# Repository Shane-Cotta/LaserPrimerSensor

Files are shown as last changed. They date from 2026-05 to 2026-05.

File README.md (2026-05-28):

# Laser Primer Sensor

A DIY fiber-optic **primer orientation / presence sensor** for the **Mark 7 Apex 10** progressive reloading press. The sensor head watches the priming station from beneath the shell plate; if a primer is missing or sitting wrong, the amplifier flips its output and signals the press to stop before it indexes to the next station.

It's a DIY alternative to a commercial primer sensor, built from off-the-shelf parts and **two 3D-printed housings**:

- **Fiber Module Housing** — holds the RS320-TZ-M3 fiber head and mounts **under the shell plate**, aimed at the priming station.
- **In-Line Module Housing** — the electronics enclosure (amplifier, boost converter, opto-isolator). It mounts remotely — **zip-tied to the case feeder pole** or simply **set on the workbench** near the press — with the fiber and signal cable running back to the fiber head and the press.

> ⚠️ **This is a hobbyist project shared as-is, with no warranty.** A DIY sensor is a backstop, not a substitute for safe reloading practice and visual inspection. Test thoroughly with dummy/empty cases before live loading, and follow Mark 7's guidance for wiring anything into your press. You are responsible for your own machine and your own safety.

---

## How it works

The **RS320-TZ-M3** right-angle fiber head is a diffuse-reflective probe: it emits light from one fiber and reads the light bounced back into the other. A correctly seated, right-side-up primer reflects a different amount of light than an empty pocket or an upside-down/missing primer.

The **FS-N18** amplifier reads that reflected intensity as a 0–9999 value and compares it to a threshold. Run in **Dark-ON** mode with a threshold around **3950** (your tuned value), it switches its output based on whether the reflected light is above or below the set point. That output is passed through a **PC817 opto-isolator** — which galvanically isolates the sensor from the press electronics — and then into the Apex 10's sensor/stop input.

The **XL6019** boost converter takes the Apex 10 / AutoDrive board's **5 V** and steps it up to the **12 V** the FS-N18 needs. The amplifier's output is **NPN** (open-collector, switching to ground), and the **PC817 opto-isolator** bridges that 12 V signal back down to the board's 5 V SIGNAL terminal using an internal light path — so there's no direct electrical connection between the sensor side and the press electronics.

---

## Bill of materials

| # | Part | Qty | Notes |
|---|---|-----|---|
| 1 | BOJKEON **FS-N18** dual-display fiber optic amplifier — [link](https://www.amazon.com/dp/B0DMW48CJ2) | 1 | 12–24 VDC, NPN/PNP open-collector output |
| 2 | **RS320-TZ-M3** diffuse-reflection 90° right-angle fiber head, M3 thread, 2 m lead — [link](https://www.amazon.com/dp/B0D56JZ92R) | 1 | Emit + receive fibers |
| 3 | **XL6019** 5 A adjustable DC-DC step-up (boost) module (3-pack) — [link](https://www.amazon.com/dp/B082XQC2DS) | 1 | Sets supply voltage for the amplifier |
| 4 | NOYITO **PC817** 1-channel optocoupler isolation module (12 V input version) — [link](https://www.amazon.com/dp/B0B5383L69) | 1 | Isolates the 12 V sensor signal back to the board's 5 V SIGNAL terminal |
| 5 | **In-Line Module Housing** (3D printed) | 1 | Electronics box — `hardware/In-Line_Module_Housing.step` |
| 6 | **Fiber Module Housing** (3D printed) | 1 | Holds fiber head under shell plate — `hardware/Fiber_Module_Housing.step` |
| 7 | Power | — | Taken from the **Apex 10 / AutoDrive 5 V** output (no separate adapter in the standard setup) |
| 8 | 3-pin terminal / cable to the AutoDrive sensor port | 1 | Carries 5 V, GND, and SIGNAL between the box and the board |
| 9 | Zip ties | a few | To mount the In-Line box to the case feeder pole (optional) |

**Fasteners**
- **PCB mounting (inside housing):** standard **HDD/SSD chassis screws** (6-32 / M3-class drive screws)
- **Case plate / lid:** **M4** screws
- **Fiber head:** **M3** thread (built into the RS320-TZ-M3 head; threads into the Fiber Module Housing)

> The components are third-party products sold under their own terms. This project only covers the custom housings, wiring, and documentation.

---

## 1. Print the housings

Two parts to print, both provided as STEP files (modeled in millimeters):

- `hardware/In-Line_Module_Housing.step` — the electronics box (FS-N18, XL6019, PC817)
- `hardware/Fiber_Module_Housing.step` — the under-shell-plate mount that holds the RS320-TZ-M3 fiber head

- Import into your slicer (most slicers accept STEP directly; otherwise convert to STL).
- **Material:** PETG or ABS/ASA recommended for heat and proximity to the press; PLA works for bench testing.
- **Suggested settings:** 0.2 mm layers, 3–4 perimeters, 20–30% infill.
- Orient each part so the screw holes / mounting features and the fiber bore print cleanly; add supports only if your orientation requires them.
- Test-fit the boards, the fiber head, and the screws before final assembly; tune your slicer's hole/horizontal-expansion compensation if anything comes out tight.

---

## 2. Wiring

Wiring diagram

**Signal chain:** AutoDrive 5 V → XL6019 boost (set to 12 V) → FS-N18 amplifier → (optical fiber) RS320-TZ-M3 head → primer; FS-N18 NPN output → PC817 isolator → AutoDrive SIGNAL terminal.

**5 V side — AutoDrive board to boost and opto:**

| From | To |
|---|----|
| AutoDrive 5 V out | XL6019 IN+ |
| AutoDrive 5 V out (jumper) | PC817 VCC |
| AutoDrive GND | XL6019 IN− |
| XL6019 IN− (jumper) | PC817 GND |
| PC817 OUT | AutoDrive SIGNAL in |

**12 V side — boost out to sensor and opto input:**

| From | To |
|---|----|
| XL6019 OUT+ | FS-N18 Brown (+12 V) |
| XL6019 OUT+ (jumper) | PC817 IN+ |
| XL6019 OUT− | FS-N18 Blue (0 V) |
| FS-N18 Black (NPN signal) | PC817 IN− |
| FS-N18 T ▸ / R ◂ fiber ports | RS320-TZ-M3 emit / receive fibers |

FS-N18 cable colors: **Blue = 0 V**, **Brown = +12 V**, **Black = signal output**.

Physical reference — internal wiring of the assembled unit:

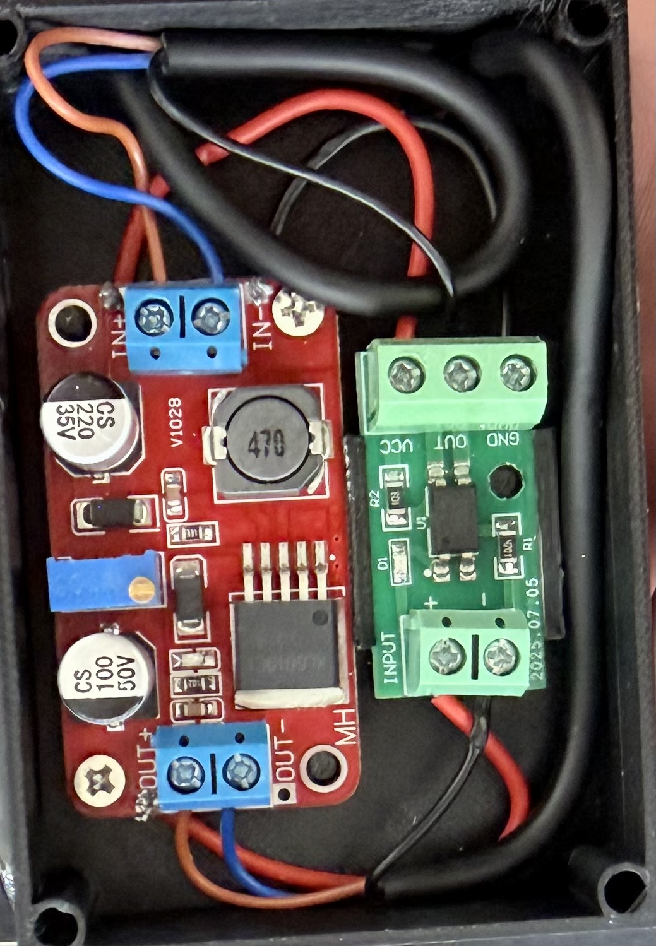
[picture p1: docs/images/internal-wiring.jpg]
Internal wiring


> ⚠️ **Confirm against your unit:** (1) that power comes from the **AutoDrive 5 V** terminal rather than a separate adapter, and (2) that the **FS-N18 output is the NPN version**. The rest of the wiring is determined by the parts.

3d reference — 3d render of the assembled pcb housing unit:
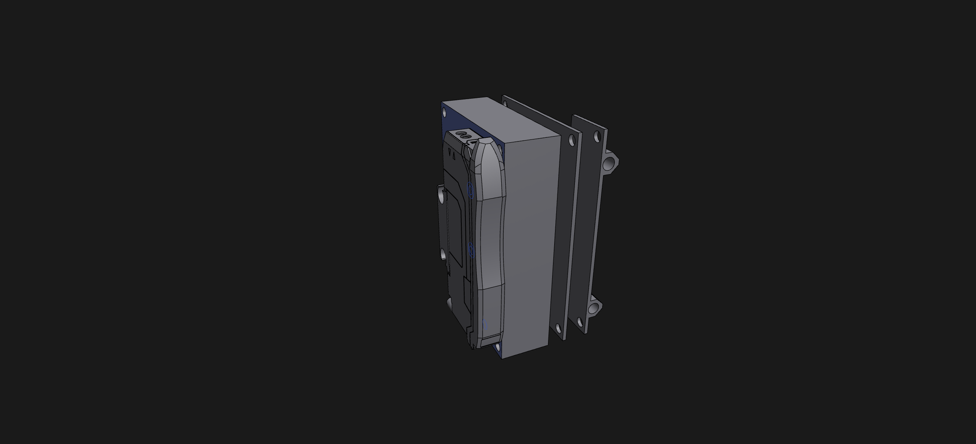
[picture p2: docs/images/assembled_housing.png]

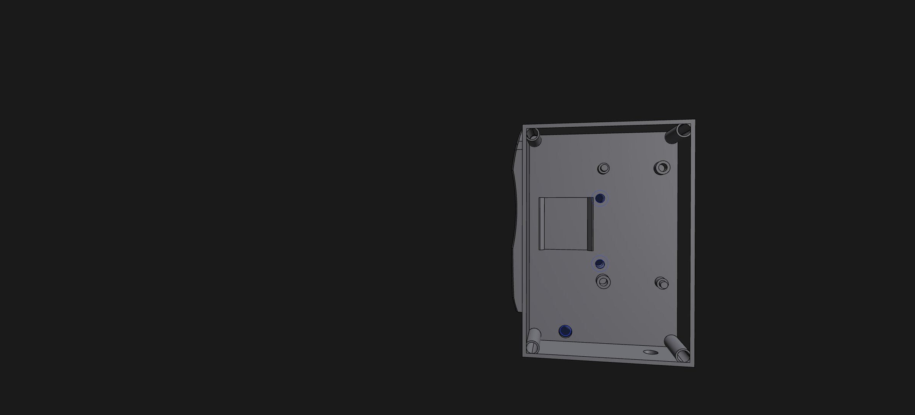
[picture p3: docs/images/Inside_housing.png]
 

3d reference — 3d render of the fiber head housing:
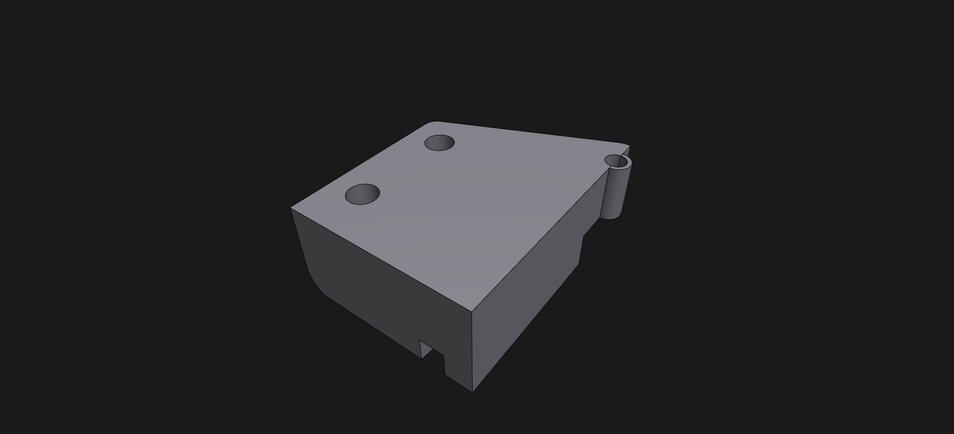
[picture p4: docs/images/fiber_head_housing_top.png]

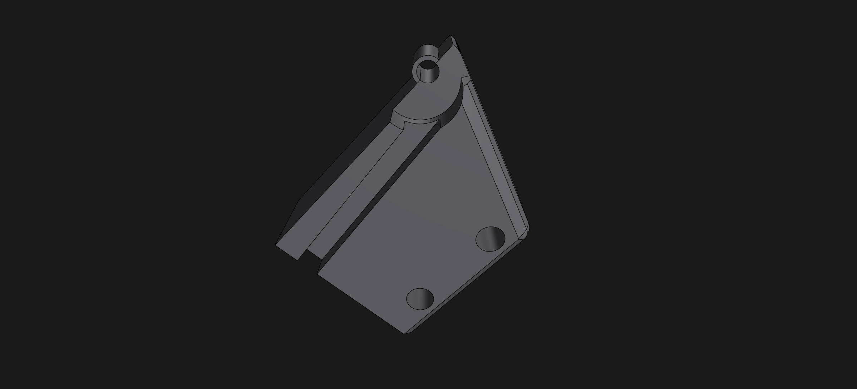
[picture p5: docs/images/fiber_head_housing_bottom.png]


Physical reference — the fiber head mounted under the shell plate, with the fiber routed back to the electronics box:
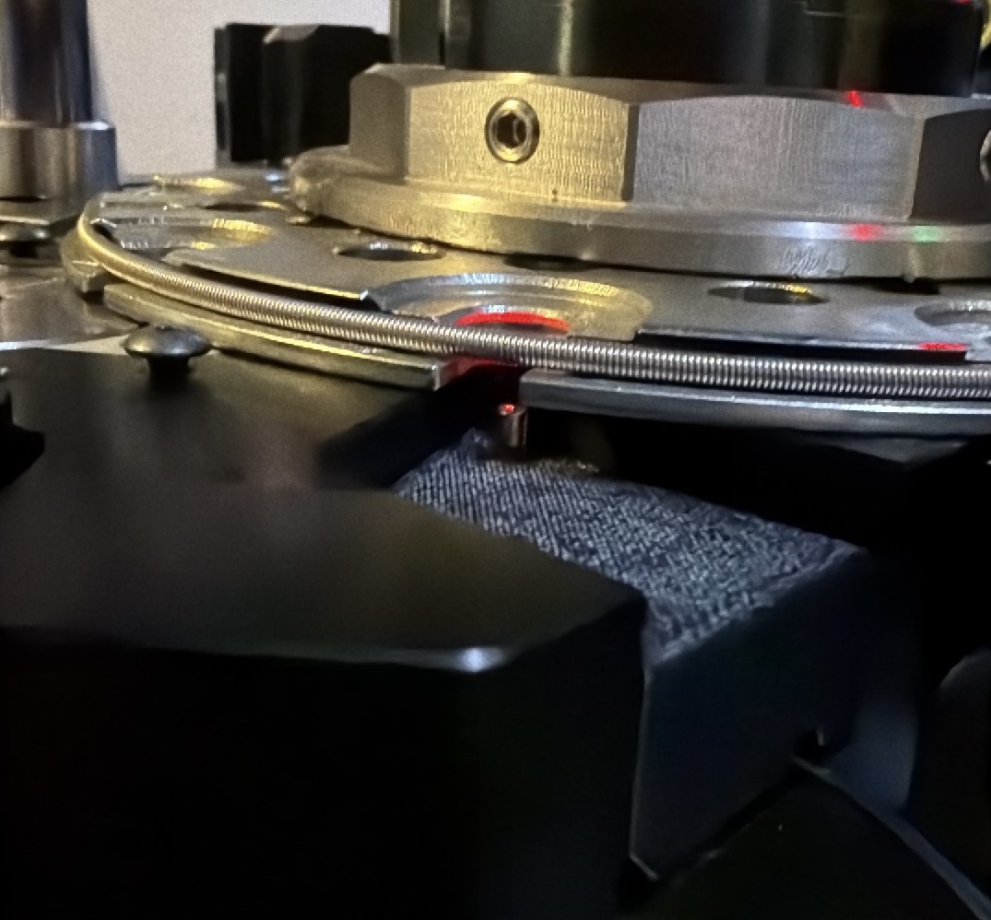
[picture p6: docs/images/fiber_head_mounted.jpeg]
Fiber head mounted


Physical reference — the assembled unit ready for mounting to the press:
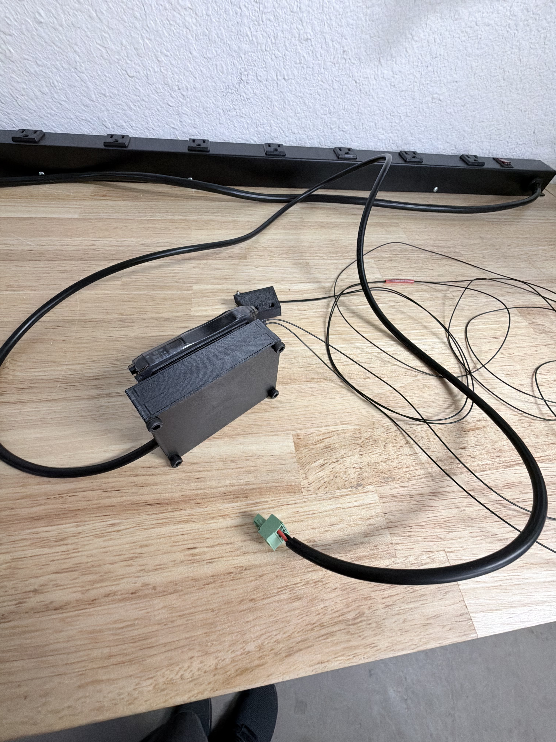
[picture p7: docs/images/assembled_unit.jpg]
Assembled unit


---

## 3. Assembly

**Electronics — In-Line Module Housing:**
1. Set the XL6019 boost output to **12.0 V before** wiring it to anything else: feed it from the AutoDrive 5 V (power the board by USB only, nothing else connected), turn the trim pot while watching a multimeter on OUT+/OUT− until it reads 12.0 V, then disconnect power. (Getting this right first prevents most wiring headaches.)
2. Mount the XL6019 and PC817 boards inside the In-Line housing using the **HDD/SSD chassis screws** into the printed bosses.
3. Seat the FS-N18 amplifier in its pocket and route its cable to the boards per the connection table.
4. Make the wiring connections (boost → amp power, amp output → opto input, opto output → press pigtail through the 2-pin terminal).
5. Insert the RS320-TZ-M3 fibers into the FS-N18's T (transmit) and R (receive) ports, following the fiber-insertion marker and locking lever on the amplifier.
6. Close the case plate and secure with the **M4** screws.

**Fiber head — Fiber Module Housing:**
7. Fit the RS320-TZ-M3 threaded fiber head into the Fiber Module Housing so the optical face points at the primer pocket; lock the standoff with the head's nut.
8. Leave enough fiber slack to route from the under-shell-plate mount back to the electronics box.

---

## 4. Mount to the Apex 10

**Fiber Module Housing (under the shell plate):**
1. Mount it beneath the shell plate so the **RS320-TZ-M3 head aims at the priming station** — where you want to confirm primer presence/orientation.
2. Secure it so the head holds a consistent, repeatable distance and angle to the primer pocket. Consistency here is everything for reliable triggering.

**In-Line Module Housing (electronics — remote):**
3. Mount the electronics box where it's convenient and out of the way: **zip-tie it to the case feeder pole**, or just set it on the bench next to the press.
4. Route the **optical fiber** from the fiber housing back to the electronics box, and the **isolated output cable** from the box to the press's sensor/stop input.
5. Keep the fiber and cables clear of moving parts and the indexing motion, with a little slack so nothing pulls tight on a stroke.

> **Eye safety:** the fiber head emits a visible beam. Don't stare into it or aim it at eye level during setup, and verify alignment with the press unpowered where you can.

---

## 5. Configure the FS-N18

Mode and threshold (general setup): **Dark-ON**, threshold ≈ **3950**. Tune to your own optics and lighting.

**Two-point teach (recommended):**
1. With **no primer / empty pocket** in front of the head, press **SET** (hold < 2 s).
2. Place a **correctly oriented primer** at the station, press **SET** again to complete.

**Other settings to dial in:**
- **Output type:** set to **NPN** (open-collector to ground) to match the PC817 input wiring and the AutoDrive board.
- **Response time (P0–P4):** faster (P0/P1) catches the primer during the brief dwell; slower modes reject noise. Match to your press speed.
- **Output mode:** Light-ON vs Dark-ON (use Dark-ON).
- **Delay/timer:** On/Off/One-shot delay (1–9999 ms) if you need to time the read to the dwell.
- **FEC (F1–F4):** if you add a second amplifier nearby, set them to different FEC channels to prevent mutual interference.
- **Keyboard lockout:** lock the keys after tuning so settings don't drift.

---

## 6. Connect to the press

The PC817 output side ties into the Apex 10's 3-pin sensor port: **OUT → SIGNAL**, **VCC → 5 V**, **GND → GND** (the same 5 V and GND that feed the boost input). A fault — missing or misoriented primer — switches the signal so the press halts before it indexes to the next station. You can disable the sensor from the Mark 7 tablet when processing brass without primers.

---

## Troubleshooting

- **No switching / value stuck:** check the boost output voltage and FS-N18 power (Brown/Blue); confirm fibers are fully seated and the lock lever is down.
- **Triggers inconsistently:** the head standoff/angle is probably varying — tighten the mount; re-run the two-point teach; nudge the threshold.
- **False trips at speed:** try a faster response mode (P0/P1) or add a short on-delay to align the read with the dwell.
- **Press doesn't see the signal:** check PC817 output polarity and that the press input is enabled and wired for the right active level.

---

## Support the Project

If this project helped you on your reloading journey, saved you some troubleshooting time, or inspired your own DIY build, and you'd like to support continued development and experimentation, you can do so here:

[Support the Project](https://donate.stripe.com/9B69AT9jK94z3j71312Ji00)

## License

This project's original work — including the custom 3D-printable housing designs, wiring diagram, photos, assembly instructions, and documentation — is licensed under the:

**Creative Commons Attribution-NonCommercial-ShareAlike 4.0 International License (CC BY-NC-SA 4.0)**

You are free to:
- **Share** — copy and redistribute the material in any medium or format
- **Adapt** — remix, transform, and build upon the material

Under the following terms:
- **Attribution** — You must give appropriate credit and indicate if changes were made.
- **NonCommercial** — You may not use the material for commercial purposes.
- **ShareAlike** — If you remix, transform, and build upon the material, you must distribute your contributions under the same license.
- **No additional restrictions** — You may not apply legal terms or technological measures that legally restrict others from doing anything the license permits.

Full license text:  
https://creativecommons.org/licenses/by-nc-sa/4.0/

### Scope of this license

This license applies only to the original project materials contained in this repository, including:
- 3D housing designs
- STEP/STL/CAD files
- Wiring diagrams
- Documentation and photos
- Original assembly instructions

Third-party hardware components, manufacturer manuals, trademarks, firmware, and product names remain the property of their respective owners and are covered by their own licenses and terms.

### Attribution notice

The original wiring diagram concept and inspiration were derived from work by **B-Team Engineering (Gross Engineering LLC)**. The wiring diagram included in this repository has been adapted and redrawn for this project, with appreciation and attribution to the original source.

### Commercial use

Commercial manufacturing, resale, kit sales, paid assembly services, or redistribution of modified versions for commercial purposes are not permitted without separate written permission from the project author.

### Commercial licensing

If you are interested in manufacturing, selling kits, offering assembled units, bundling this project into commercial products, or otherwise using this work commercially, please contact the project author to discuss licensing arrangements or collaboration opportunities.

### Disclaimer

This project is provided "as is", without warranty of any kind, express or implied. Reloading ammunition and modifying automated loading equipment can be dangerous. You are solely responsible for verifying safe operation, proper wiring, and safe reloading practices before use.

Always test thoroughly with dummy or inert components before live operation.

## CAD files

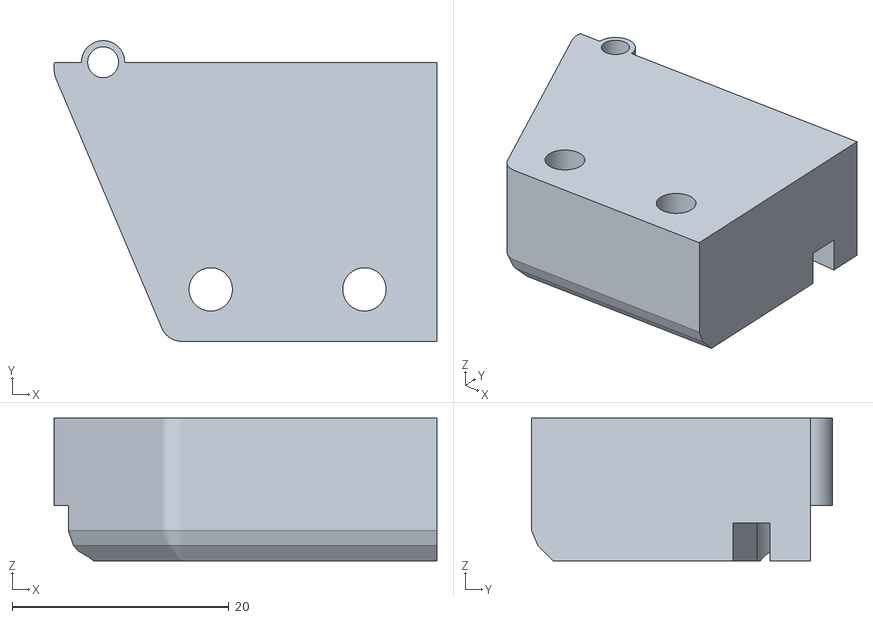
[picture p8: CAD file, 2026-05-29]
hardware/fiber_module_housing_stls/fiber_module_housing.stl
35.4 x 27.8 x 13.2

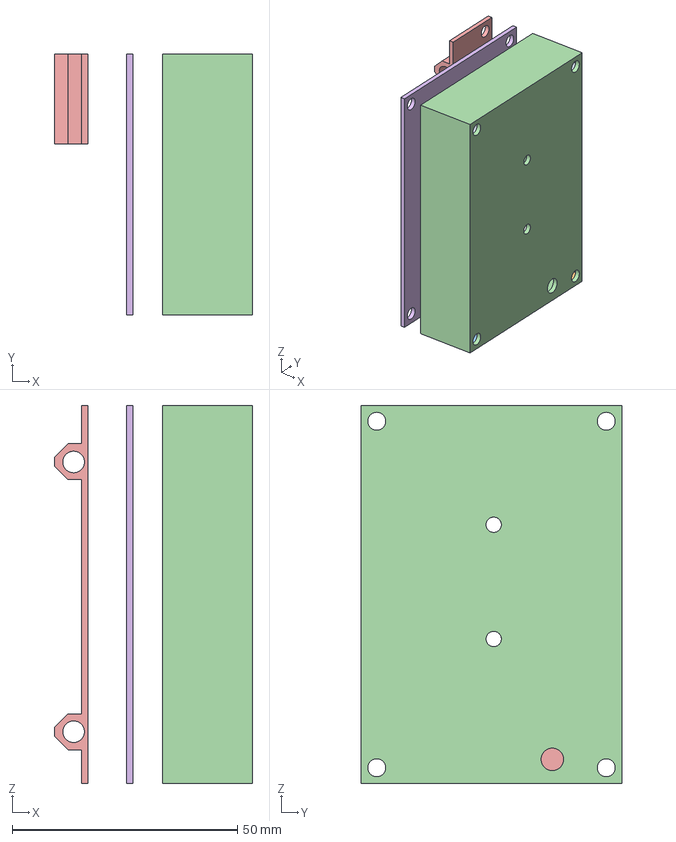
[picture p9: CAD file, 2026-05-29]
hardware/In-Line_Module_Housing.step
44.0 x 58.0 x 84.0 mm
OP-73880_2
FS-N11N_11P_13N_13P_ﾃﾞﾌｫﾙﾄ
Full Case
v2 Top
V2 Bottom
in_line_dc_step_up
Pole zip Tie Mount
in-line-lid

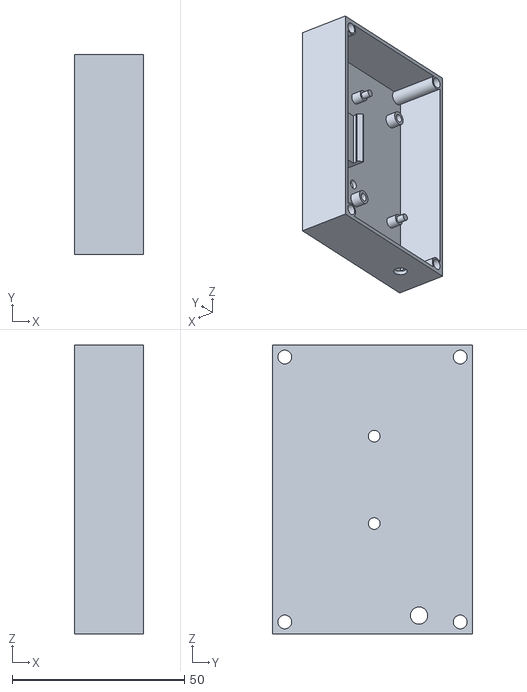
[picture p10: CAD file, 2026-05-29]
hardware/power_module_housing_stls/box.stl
20.0 x 58.0 x 84.0

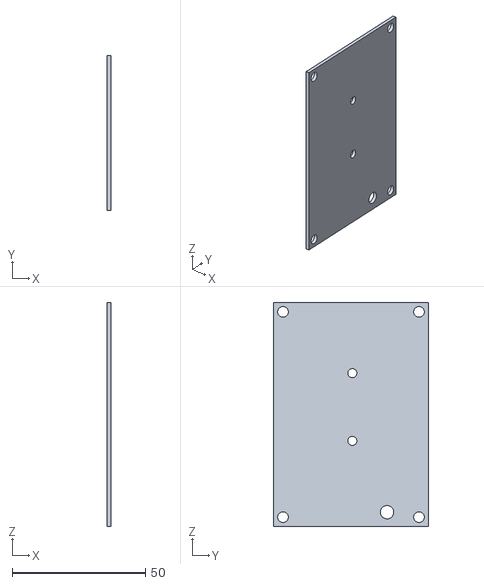
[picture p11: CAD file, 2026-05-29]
hardware/power_module_housing_stls/lid.stl
1.50 x 58.0 x 84.0

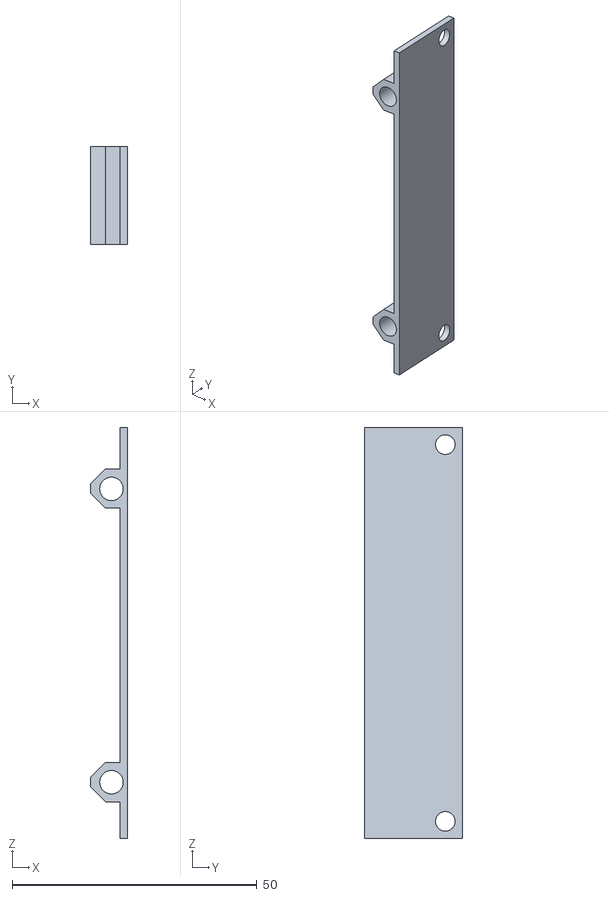
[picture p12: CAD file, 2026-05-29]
hardware/power_module_housing_stls/pole_mount.stl
7.50 x 20.0 x 84.0

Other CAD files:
hardware/Fiber_Module_Housing.step

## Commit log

2026-05-28 Refactor code structure for improved readability and maintainability
    [Fiber_Module_Housing.step, In-Line_Module_Housing.step]
2026-05-28 Update README.md to clarify configuration instructions for FS-N18 sensor
2026-05-28 Fix image filename case in README.md for inside housing reference
2026-05-28 Implement feature X to enhance user experience and fix bug Y in module Z
    [Fiber_Module_Housing.step]
2026-05-28 Implement code changes to enhance functionality and improve performance
    [Fiber_Module_Housing.step]
2026-05-28 Update README.md to clarify power source information for the sensor setup
2026-05-29 updated 3d models and included stl's
    [Fiber_Module_Housing.step, In-Line_Module_Housing.step, box.stl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]
